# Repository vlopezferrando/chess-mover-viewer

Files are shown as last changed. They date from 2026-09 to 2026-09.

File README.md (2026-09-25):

# Chess mover CAD comparison

[Compare both layouts](https://vlopezferrando.github.io/chess-mover-viewer/).

- [A: battery beside servo — Ø43 × 21.0 mm](side-by-side/): compact 100 mAh catalogue cell, KST X06N and 13 mm wheels.
- [B: battery below motors — Ø43 × 25.2 mm](bottom-battery/): Honcell 100 mAh cell and 20 mm wheels.

Both retain 6 mm magnet travel, front charging pads and a separate dock. Camera position/opening are improved; the viewers include a camera-field inspection mode. STEP downloads are available in each viewer.

[Design comparison, sources and validation](LAYOUT_COMPARISON.md).

Earlier designs: [stacked battery](battery-stacked.html), [plate-powered KST](43mm-kst-plate.html), [43 mm FS0307](43mm-fs0307.html), [45 mm](45mm.html), [40 mm](40mm.html).

Nominal CAD validation passed; electrical performance, supplier-specific cell packaging, docking retention, optical performance and fabrication tolerances remain unqualified.

Latest: [coplanar mover with wall rails](https://vlopezferrando.github.io/chess-mover-viewer/rail-dock/). See [rail concept](RAIL_DOCK.md) and [body/PCB readiness](BUILD_READINESS.md).

Detailed body: [viewer](https://vlopezferrando.github.io/chess-mover-viewer/detailed-body/), [design notes](BODY_DESIGN.md), [supplier brief](BODY_PRINT_BRIEF.md). Ø44 × 21 mm fit prototype, not a manufacturing release.

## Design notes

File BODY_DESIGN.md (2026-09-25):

# Detailed coplanar body — first fit prototype

This revision turns the packaging concept into **three separate body parts with recessed underside fasteners, motor stops, integral axle bridges, a servo/battery carrier, a camera nest and PCB capture ledges**. It is a fit-and-assembly prototype for supplier review. It is not a released powered mechanism or a finished PCB design.

## Dimensions and deliberate changes

- **Ø44 mm × 21 mm**, retaining 21.2 mm nominal floor-to-board space and 13 mm wheels. Three Ø3.6 mm screw posts need up to a 44 mm envelope at the selected clear locations; this is a local packaging result, not proof that no possible 43 mm body exists. The front is flattened at Y=-21.5 mm to preserve the rail interface.
- Battery remains beside the servo, with the existing assumed **17.6 × 14.6 × 8 mm design envelope**. Its bottom moves from 11.6 to **12.1 mm**, leaving 0.1 mm nominal roof clearance. This is *not* a confirmed swollen-cell tolerance: supplier dimensions remain a release blocker. Do not clamp a real pouch cell into an undersized pocket.
- Main shell wall **1.2 mm**, floor **0.6 mm**, lid **0.8 mm**. Wheel/optical openings and local reliefs mean those are design dimensions, not a global minimum-thickness certification.
- Equipment shelf **1 mm**; a solid **0.8 mm servo bed** reinforces it without increasing height. It replaced two narrow ribs after the first stiffness screen. Battery shelf and side/end guards retain the cell without using it as a structural support for the servo.
- Axle bridges: two **1.5 × 2.8 mm arms** per wheel, with Ø3.2 mm nominal bores. Actual axle/gear coupling and axial retention remain undecided.
- Left rear coil moves from (-11.2,13.3) to **(-12.4,12.4) mm**, 1.5 mm displacement, to clear the lid's lift-guide socket. No coil electrical design is implied.
- Camera nest supports the existing sensor/lens envelope above the entrance pupil. It does not establish a selected camera or a confirmed retention/adhesive method.
- Three low-friction anti-tip pads are modeled with **0.1 mm nominal floor clearance**. The wheels remain the nominal floor contacts; slight pitch brings a pad into contact. Actual tire compliance, pad height, floor flatness, wheel load share and traction need measurement.

## Body joint and manufacturing detail

1. **Lower chassis**: open-top motor saddles, axial end stops, integral outboard axle bridges, front charging-contact carrier and magnet pocket, three screw-bearing seats and pad recesses.
2. **Removable equipment carrier**: servo bed and case stops, battery shelf/guards, camera nest, PCB ledges, peripheral wall. Its stepped underside mates with the chassis with a **0.1 mm nominal axial seam**; this is subject to coupon calibration.
3. **Lid**: PCB capture surface, three deep threaded bosses and two lift-guide sockets. Two separate elastomer pads apply provisional servo restraint; their free/compressed dimensions are assumptions and require measured preload.

Three nominal **M1.6 × 16 socket-head screws enter from underneath**: Ø3 × 1.6 mm heads sit in open Ø3.7 mm access pockets, with bearing seats at Z=4 mm. Ø1.8 mm clearances pass through the chassis/carrier. The lid has Ø3.56 mm bosses extending down to Z=15 mm, with through Ø1.25 pilot bores intended for **post-print M1.6 tapping**, not printed threads. Nominal thread engagement is **5 mm**, and screw tips finish 1 mm below the roof. This avoids the weak thin-walled counterbore collars of an initial top-entry trial. The threaded boss has about **1.15 mm radial material** around its pilot.

No installation torque or pullout capacity is qualified. Test the resin/thread process on the coupon before assembling the body. See [HPC's screw dimensional reference](https://shop.hpceurope.com/pdf/gb/CHC.pdf); select an actual available screw/material before ordering hardware.

The lid guide sockets have **0.4 mm nominal radial walls** (Ø2.5 outside, Ø1.7 bore), and only about 1 mm pin bonding length. They are explicitly a delicate feature requiring supplier review and retention/load tests. If unsuitable, use separate metal bushings or enlarge/reposition these mounts; do not infer strength from successful STL export. The print pack excludes the small gears, wheels, crank, tray and pins because their manufacturing interfaces are not yet detailed.

Charging contacts remain custom spring envelopes; the new carrier anchors their support to the chassis. Power rail force, contact wear, magnet retention/release and electrical charging remain unvalidated. The PCB outline now reserves screw/guide clearance and a through-pocket over the raised battery; the largest connected board region is retained. It is still not routed or proof that all circuitry fits.

## Assembly sequence to evaluate

1. Inspect and calibrate bores/joints using the coupon. Clean/cure parts using the service's specified process, tap pilot holes and verify them with screws before installing electronics.
2. Install the reference motor/gear/wheel/axle assemblies in the lower chassis; verify end-stop and saddle fits. **Shaft shortening, wheel/gear fixation and axle end retention still need exact manufactured parts**, so this currently means a fit trial, not permission to run loose gears.
3. Assemble the servo, crank, pin and magnet carriage as a module **outside the carrier**. The reference crank has no completed spline/pin-retention detail. This subassembly must be engineered before a powered build; the body assumes it can be supplied as an assembled module.
4. Lower that module into the separate equipment carrier. Fit the camera into its nest and place the battery with its leads through the rear guard openings. Establish real sensor and cell retention after selecting those parts.
5. Place the equipped carrier onto the motor chassis, with calibrated motor shims. Route leads before closing: shown channels are allowances, not a complete harness design. The body must not pinch leads or press battery terminals against the shell.
6. Place the PCB on the ledges, then lower the lid and its guide pins through the guide clearances/carriage. Hold the stack in a soft assembly fixture and install the three screws from underneath through the checked tool paths. First dry-assemble without the battery so loose parts cannot fall onto it. Test the actual guide fit before bonding pins.
7. Verify unpowered wheel freedom, lift travel, contact alignment and camera view. Perform load/retention tests before powering motors or servo.

Sampled straight insertion checks cover the servo/lift module into an empty carrier, equipped carrier onto the chassis/drive, and lid/guide insertion with the remaining assembly present. They do not validate all manual operations, lead bends, finger access, camera adhesive, servo spline or the reference drivetrain's unresolved joints.

## Initial force calculations

`src/force_screen.py` uses SI units and writes JSON/CSV. It is **analytical screening, not FEA**:

- Existing magnetic sample: 0.366 N for a 10 × 2 N42 magnet at 3.6 mm gap and 4 mm lateral offset; motor/servo steel was absent from that simulation.
- With assumed 0.1 N guide resistance, 50% efficiency and factor 3: **12.50 mN·m lift torque screen**. This is not a measured worst-case demand or a check of the supplied servo voltage/duty cycle.
- Revised solid servo bed: approximately **0.009–0.046 mm deflection** across assumed E=1–2.5 GPa and 50–100% effective stiffness, versus a provisional 0.05 mm budget. Midspan beam stress is about 0.74–1.48 MPa; no allowable material strength or certified safety factor is assigned.
- Axle-arm screen: approximately **0.004–0.019 mm deflection**, sweeping assumed 30–60 g mover masses, 5 g vertical loading and equal wheel/arm sharing. Actual mover mass is not established.

The stepped servo-bed beam includes its thinner end sections. Its supports/load sharing and the axle-arm idealization still omit 3D notches, contact preload, warpage, creep, printed anisotropy and adhesive strength. These results justified geometry changes but do not qualify the body. Measure bed compliance, axle alignment, guide binding, thread pullout and the actual lift load in the assembled chassis.

## Reproduce

Use the pinned environment in `../cad_10_coplanar/requirements.txt` and the existing setup instructions in `../cad_01_mover/README.md`. At repository root:

```sh
MPLCONFIGDIR=/tmp/mover-mpl cad_01_mover/.venv/bin/python -m cad_13_body.src.build
cad_01_mover/.venv/bin/python -m cad_13_body.src.validate
cad_01_mover/.venv/bin/python -m cad_13_body.src.check_dock
cad_01_mover/.venv/bin/python -m cad_13_body.src.check_exports
MPLCONFIGDIR=/tmp/mover-mpl cad_01_mover/.venv/bin/python -m cad_13_body.src.camera_study
cad_01_mover/.venv/bin/python -m cad_13_body.src.force_screen
MPLCONFIGDIR=/tmp/mover-mpl cad_01_mover/.venv/bin/python -m cad_13_body.src.interface_drawing
cad_01_mover/.venv/bin/python -m unittest discover -s cad_13_body/tests
node cad_13_body/src/check_viewer.cjs
```

Open `output/mover_viewer.html` and choose **Inspect body parts** or **Explode body assembly**. The exploded view explains the structure, not a collision-free assembly trajectory. STEP assemblies, separate body STEP/STL, coupon, force screens and geometric reports live in `output/`. The STL ZIP is named **body_fit_prototype.zip** deliberately. Read [PRINT_BRIEF.md](BODY_PRINT_BRIEF.md) before requesting manufacture. No quote has been requested and nothing has been ordered.

## Final nominal checks

54 valid connected modeled parts; 12 lift poses, 24 insertion samples and three underside driver paths pass. Fifteen rail approach/parking samples pass. Each of the three body STEP files reimports as one valid solid within Ø44 mm; all four STL files (including coupon) are watertight under the mesh edge check. Intentional screw/pilot overlap represents unmodeled threads and is recorded separately. Camera geometric clear area is 118.4 mm² versus 110.1 mm² previously, under the same assumed lens model; actual optics remain unqualified. Three analytical-formula tests and the viewer-control stub pass; no live-browser rendering test was performed.

Build commands refer to the local engineering source workspace. This viewer repository contains exported artifacts, not a standalone copy of the complete source project.

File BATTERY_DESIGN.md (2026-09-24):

# Battery mover and charging dock — Ø43 × 25.2 mm

[Open the offline viewer](index.html). Use **Inspect battery**, **Show docking station**, the docking-distance slider, and the independent enclosure/lid layers. Downloads include [mover STEP](mover_step.zip), [dock STEP](dock.step).

This is a nominal packaging design. The battery is a documented reference cell, while charging electronics and dock contacts are space allowances, not a complete electrical or manufacturable design. Prior iterations remain unchanged.

## Dimensions and changes

| Quantity | Previous plate-powered KST | Battery version |
|---|---:|---:|
| Outside diameter | 43 mm | **43 mm** |
| Highest mover geometry above floor | 20.0 mm including contacts | **25.2 mm** |
| Floor-to-board underside | 20.0 mm | **25.4 mm** |
| PCB top | 19.0 mm | 24.4 mm |
| Servo case top | 18.8 mm | 24.2 mm |
| Magnet / coil top | 19.5 mm | 24.9 mm |
| Camera lens height | 11.9 mm | **11.9 mm** |
| Magnet and stroke | 10 × 2 mm N42 / 6 mm | unchanged |
| Wheels | 13 mm | unchanged |
| Battery | none | 100 mAh, 1S, supplier-rated 2 A maximum continuous |

The 100 mAh cell sits horizontally above the drive motors. The servo, roof PCB and lift move upward together by 5.4 mm. Removing top/bottom sliding contacts means the new mover's highest geometry is its lid, 0.2 mm below the board underside. Thus the mover-height increase is 5.2 mm, and required floor-to-board space increases by 5.4 mm. The battery is not placed over the camera or in the magnet travel path.

The cradle includes edge guards and two hangers reaching the roof. A relief in the old motor saddle clears the shelf. The downward camera stays in place with longer supports and a flex routing allowance. Four top coils, KST X06, two N20 motors, transmission and optional shell remain. The front shell gains a recessed docking-pad carrier. Continuous upper/lower conducting sheets and all four sliding contacts are removed.

### Space budget

- Battery body: x = −16…13 mm; y = −8.25…7.25 mm; z = **11.6…16.35 mm**.
- Supplier maximum thickness: **4.4 mm at delivery, 4.75 mm after cycling**. The viewer uses 4.75 mm, not an unrealistically thin new-cell-only envelope.
- Shelf: z = 11.2…11.5 mm; **0.3 mm above the nominal motor top**, and 0.1 mm below the cell. This thin shelf still needs strength and insulation design.
- Lowest servo rail: z = 16.6 mm, leaving **0.25 mm over the cycled cell envelope**. Do not clamp or load the cell with the servo.
- Straight battery tab allowances: maximum **7 mm length and 2.2 mm width**; nominal tab spacing represented. Weld insulation, tab-location tolerances and final lead bends require supplier confirmation. We do not assume folded tabs save space.
- Added electronics allowances: **9 × 6 × 1.4 mm** charger/protection/charge-tracking area and **6 × 7 × 2 mm** boost-converter/inductor area. Existing ESP32, motor-driver and memory allowances remain. These are not validated component placement/routing or thermal results.
- A local height study compares 25.2, 25.0 and 24.8 mm while preserving this shelf and moving the upper mechanism. The 25.0 mm trial leaves only 0.05 mm battery-to-rail clearance; 24.8 mm overlaps. The selected 25.2 mm uses a provisional 0.25 mm nominal gap. This is **not a full manufacturing tolerance budget or proof of a global minimum**.

See `output/space_study.json` and `output/height_comparison.csv`. The old 20 mm upper layout is also tested against the new cell envelope, exposing its collisions. A larger diameter might permit side-by-side repacking; that search is outside this local study.

## Reference battery and power constraints

Reference: **Honcell HCG431528HP20 / HCG-431528**, 100 mAh, 3.7 V nominal, approximately 2.9 g, bare cell. [Manufacturer page](https://www.honcell.com/lithium-battery/cells/hcg-lipo-battery-cells/1933) and [2024 manufacturer datasheet](https://www.honcell.com/Public/Uploads/uploadfile/files/20240809/DATASHEETHCG4315283.7V100mAhCELL2024.pdf); saved in `sources/honcell_100mah.pdf` with an inspected drawing render. Dimensions include the complete body/seal envelope, but exclude the separately modeled tabs.

The sheet specifies 2 A maximum continuous discharge at 10–45°C. Its 4 A pulse figure is only **2–3 milliseconds**; it is not permission to run stalled motors at 4 A. The final motor winding, drive-current limiting, converter losses, servo transient and coil load must fit the battery budget. At 3.0 V and 85% converter efficiency, 2 A would provide only 5.1 W; practical limits need margin for voltage sag and temperature. The reference cell is not yet purchased or electrically tested.

Use a regulated servo supply: a 1S cell cannot provide a steady 6 V. Reserve cell protection, temperature sensing, charger power-path management and reverse-current blocking. CAD does not implement these circuits. No battery connector is claimed to fit; supplier-welded tabs/leads are represented, with service access requiring detail design.

A 150 mAh cell is not automatically interchangeable. The sourced [Blade BLH4210 150 mAh high-discharge battery](https://www.horizonhobby.com/product/150mah-1s-3.7v-45c-lipo-battery-ph-1.25-ultra-micro/BLH4210.html) is 42 × 12 × 5 mm: its 43.68 mm footprint diagonal exceeds the 41.4 mm shell bore. This build therefore implements the documented **100 mAh** reference. A shorter 150 mAh alternative would require its own drawing and clearance checks.

## Docking contacts and operation

Two **3 × 3 mm mover pads**, on 7 mm centre spacing, face forward (−Y). Their exposed plane is y = −20.5 mm, with z centre 9.5 mm. They are recessed within the 43 mm circular envelope and connect to the **charger input**, not directly across the bare battery. Polarity in the model: x = −3.5 is GND; x = +3.5 is +5 V. PCB-mounted or flex-mounted plated pads on an insulating carrier are intended; finish, termination and fastening are provisional.

The external dock has two axial spring-contact envelopes and approach rails. Spring barrels are on the station, saving mover volume. Modeled compressed tips touch the pad planes. The concept allocates approximately 1 mm working compression, but no purchased contact, spring rate, retention force or free-tip CAD has been selected. The 1.2 mm tips have a geometric ±0.9 mm pad-centering allowance before an entire tip leaves a 3 mm square; this is not demonstrated docking accuracy. The nominal dock footprint is 50 × 31 mm, outside the mover boundary.

The viewer's docking slider moves the mover 0–45 mm along +Y away from the seated pose. This is ideal kinematic inspection, not automatic navigation. `check_dock.py` tests sampled straight approaches against the fixed, compressed dock geometry and verifies pad/tip surface alignment. It does not simulate contact compression, yaw error, bounce or electrical connection. **A passive detent or other holding arrangement is still needed** if spring force can push the mover away; holding stalled drive motors while charging is not assumed acceptable. The shell and dock remain concept geometry, not ready-to-print fixtures.

Intended charging sequence: lower magnet, approach a perimeter marker, align slowly, establish contact, confirm input voltage/charge status, disable drives and sleep unnecessary loads, then undock with an energy reserve. Tentative standard charge current is **100 mA (1C)**; full CC/CV charging is not instantaneous. Temperature limits and supplier initial-charge instructions apply. The 200 mA maximum rating is not the default charging setting. Each mover requires its own charge controller. Low-battery detection should combine voltage under known load with charge tracking; voltage alone during acceleration is not a precise state-of-charge estimate.

## Magnet, coils and remaining limitations

Without the former 0.1 mm copper layer, nominal magnet-to-steel distance is **3.5 mm engaged and 9.5 mm retracted** (0.5 mm clearance + 3 mm nonmagnetic board + lift). Existing magnetic force/release calculations used 3.6/9.6 mm; they have **not** been rerun or requalified here. Battery pouch metal, motor steel, servo gears and PCB copper remain omitted from that FEM. Coil resonance, battery heating and RF behaviour need measurement in the new stack.

The previously targeted **150 mm/s** is retained but not demonstrated. Battery current limits could affect acceleration and available torque. Full tolerance stack, heat flow, pouch protection, wire bends, fasteners, snap features, servo-horn retention, optical field of view and close focus remain unresolved. Carry forward the KST crank/spline and thin carrier limitations in [iteration 8](https://github.com/vlopezferrando/chess-mover-viewer/blob/main/ACTUATOR_STUDY.md).

## Reproduce and validation

From the repository root:

```sh
cad_01_mover/.venv/bin/python -m cad_09_battery.src.build
cad_01_mover/.venv/bin/python -m cad_09_battery.src.validate
cad_01_mover/.venv/bin/python -m cad_09_battery.src.space_study
cad_01_mover/.venv/bin/python -m cad_09_battery.src.check_dock
cad_01_mover/.venv/bin/python -m cad_09_battery.src.check_step
node cad_09_battery/src/check_viewer.cjs
```

Uses the pinned CAD dependencies in `requirements.txt`, the original motor asset and earlier gear/mesh utilities. Geometry dimensions are in millimetres. `parameters.json` is generated metadata, not a separate input file. `build.py` is the authoritative parametric layout.

Reports in `output/`: part validity/connectedness and interference checks, 23 lift poses, 26 gear phases, cylindrical containment, camera centre path, STEP round-trip, local height study, nine dock-approach poses and viewer-control checks. Overlap reporting threshold is 0.01 mm³. These are sampled nominal geometry checks, not continuous-motion or fabrication qualification. Viewer controls use DOM/WebGL stubs; static PNGs are visually inspected. No real-browser rendering test is claimed.

The selected build passed all listed nominal checks: 52 valid connected mover solids, no reported static/lift/gear overlaps, 43 × 43 × 25.2 mm STEP bounds, clear camera centre path and nine clear sampled dock approaches. The local 25.0/24.8 mm alternatives fail the selected battery-clearance criterion. Static overview, battery, docking and underside previews were visually inspected.

Shared viewer: https://vlopezferrando.github.io/chess-mover-viewer/ . Earlier plate-powered KST version: `43mm-kst-plate.html`.

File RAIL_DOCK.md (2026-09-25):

# Coplanar mover with wall-rail charging

Chosen architecture: Ø43 × 21.0 mm, 21.2 mm floor-to-board, 100 mAh catalogue battery beside KST X06N, 13 mm wheels, 10 × 2 mm piece magnet with 6 mm lift. This is a **packaging concept, not a manufacturing release**. Existing battery, lens, motor, PCB and structural caveats from [iteration 10](LAYOUT_COMPARISON.md) still apply.

## Charging arrangement

Two mover contacts share a vertical column at X=0, facing the front wall:

| Element | Height above floor | Nominal geometry |
|---|---:|---|
| Separate retaining magnet | 4 mm centre | Ø3 × 1 mm; packaging placeholder |
| GND contact | 8 mm centre | Custom compliant leaf allowance |
| +5 V charger input | 13.5 mm centre | Custom compliant leaf allowance |

The station has 100 mm long horizontal rails, 2.4 mm high, separated by insulating backing, plus a separate 3.4 mm high passive steel strip. The magnet-to-steel gap is 0.95 mm at the seated pose. Two insulating strips limit nominal overtravel against the shell. Rail materials/finish, contact material, preload, magnet grade/force, fasteners and tolerances remain unspecified. The spring geometry depicts a nominal seated position; it is neither a purchased part nor an elastic calculation. Its 6 mm leaf span and 0.08 mm thickness are packaging allowances only. The square tip is a stand-in for a rounded wiping contact.

The mover can park **anywhere along an equipped straight wall, facing it**. This is not charging at arbitrary room positions or headings. Wall corners, rail joins, yaw capture and end stops need separate design. Neither a continuous steel strip nor a round shell passively selects the correct heading: floor-marker navigation must align it. The along-rail slider illustrates different parking positions, not a sliding-while-charging recommendation.

Recommended first experiment: small recessed mover magnet against passive steel, with gold-plated low-force wiping contacts. Keep retention electrically separate from the power rails. Tune the retaining force through recess/gap changes. The displayed 3 × 1 mm magnet has **no verified force prediction**. Do not order it solely from this CAD.

## Why not just magnetic tape on the wall?

Magnetic rails exist. [FIRST4MAGNETS](https://www.first4magnets.com/comparing-our-flexible-adhesive-range) distinguishes ferrite magnetic tape, neodymium magnetic tape and passive steel tape. Magnetic tape plus a steel mover keeper is a plausible alternative that removes the extra permanent magnet from the mover. However, holding force varies with material, pole pattern, overlap and gap, and introduces a permanent magnetic field along the wall. Discrete wall magnets could instead produce preferred docking locations. Passive steel still interacts with the piece-carrying magnet, so either arrangement requires a full-assembly magnetic check, especially with that magnet lowered. Extra mover magnets can also attract other movers and ferrous debris; weak retention is preferable.

Compact commercial contacts are not automatically soft: [Harwin's catalogue](https://cdn.harwin.com/pdfs/Harwin_Product_Catalog_page_278.pdf) lists 0.49 N working force for S7131-45R. Two such contacts would require roughly 0.98 N just to counteract their springs. This is an example, **not a selected part**. A smaller current requirement does not itself guarantee a reliable low-force contact.

A holding magnet must exceed both contact spring forces plus disturbance margin. During retreat, springs initially assist separation; after they unload, the wheels must overcome the remaining magnetic attraction. Thus evaluate the entire force-versus-distance curve:

`required wheel force(d) = max(0, F_magnet(d) - sum(F_spring(d))) + rolling resistance`

Compare it with `min(2 * wheel_torque / wheel_radius, tire_mu * driven_wheel_normal_load)`. Motor torque, tire friction and wheel load are not yet measured. Also check pitch moments because the retaining magnet and contacts act at different heights; the nominal insulating stops do not prove stability. Pull ratings at ideal contact cannot establish this result: [K&J's test explanation](https://www.kjmagnetics.com/blog/testing-magnet-strength) describes thick steel and zero-gap conditions and the effect of gaps.

Bench acceptance: both contacts remain inside their rated compression range, contact voltage drop is within charger headroom, charging is stable across repeated placements, and the mover backs away at low battery without wheel slip. Test rail dirt/oxidation and tolerance extremes. Use current-limited rail supply, input protection and a real 1S charger/protection circuit, not direct battery connection. Rail current must cover simultaneously docked movers. Set charge current from the actual cell specification; 100 mAh capacity is not a charge-current rating. Exact supply, charge current and circuit remain undecided.

## Reproduce and inspect

Use the existing CadQuery environment from `cad_01_mover/README.md`, at repository root:

```sh
MPLCONFIGDIR=/tmp/mover-mpl cad_01_mover/.venv/bin/python -m cad_12_rail_dock.src.build
cad_01_mover/.venv/bin/python -m cad_12_rail_dock.src.validate
cad_01_mover/.venv/bin/python -m cad_12_rail_dock.src.check_dock
cad_01_mover/.venv/bin/python -m cad_12_rail_dock.src.check_step
MPLCONFIGDIR=/tmp/mover-mpl cad_01_mover/.venv/bin/python -m cad_12_rail_dock.src.camera_study
node cad_12_rail_dock/src/check_viewer.cjs
```

Open `output/mover_viewer.html`; choose **Show docking station**, then **Position along wall rail**. STEP assemblies, the rail assembly, shell STEP/STL files and checks are in `output/`. Shell STL export means a meshed CAD shape exists, not that the body is fabrication-ready. Existing and revised camera silhouettes are compared using the same assumed 60° × 45° lens; real close focus and optical recognition remain unverified. Viewer checks execute controls against a stub, not an actual browser rendering test.

See [BUILD_READINESS.md](BUILD_READINESS.md) for what separates this layout from a printable functional body and a routed PCB.

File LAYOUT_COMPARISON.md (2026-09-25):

# Two battery layouts: side-by-side and below the motors

[Open A: side-by-side](side-by-side/index.html) · [Open B: bottom battery](bottom-battery/index.html) · [Camera comparison](side-by-side/camera_comparison.png)

Both are separate parametric CAD assemblies with STEP downloads, optional shell/lid, docking pads, a dock, full 6 mm magnet travel and 100 mAh reference batteries. They are packaging candidates, not production-ready or electrically validated hardware. The earlier stack remains in `cad_09_battery`.

## Result

| Quantity | Previous stack | A: battery beside servo | B: battery below motors |
|---|---:|---:|---:|
| Diameter | 43 mm | **43 mm** | **43 mm** |
| Mover height | 25.2 mm | **21.0 mm** | **25.2 mm** |
| Floor-to-board spacing | 25.4 mm | **21.2 mm** | **25.4 mm** |
| Wheel diameter | 13 mm | 13 mm | **20 mm** |
| Motor shaft height | 5.9 mm | 5.9 mm | **11.3 mm** |
| Camera lens height | 11.9 mm | **12.8 mm** | **16.0 mm** |
| Camera XY | (5, −13.5) | (0, −15.8) | (0, −15.8) |
| Floor window | Ø10 mm | **16 × 10 mm ellipse** | **16 × 10 mm ellipse** |
| Geometrically visible floor, assumed 60° × 45° lens | 61.8 mm² | **110.1 mm²** | **125.4 mm²** |
| RPM required for 150 mm/s, 1:1 transmission | 220 | 220 | **143** |

A saves **4.2 mm / 16.7% height** versus the previous battery stack. Motors remain in the lower layer; battery and servo share the upper layer. B trades height for larger wheels, a higher camera and a low battery. It does not reduce height versus the previous stack.

## A: put a thicker, shorter battery beside the servo

The previous thin cell's 29 × 15.5 mm body is awkward to pack beside the actuator. A manufacturer catalogue lists **LiPol LPHD7214017**, 100 mAh, 20C, **17 × 14 × 7.2 mm**. Its thicker body occupies much less plan area. Source: [LiPol manufacturer catalogue](https://www.lipolbattery.com/High-Discharge-20C-Lithium-Polymer-Battery-for-Camera-Drone.html), preserved as `sources/lipol_catalogue.html`.

This is a **catalogue candidate**, not a selected production cell. No individual supplier drawing, tab dimensions, availability confirmation, temperature-dependent discharge data or cycled-thickness specification has been obtained. The CAD uses an explicit **17.6 × 14.6 × 8.0 mm design envelope**, allowing 0.6 mm extra length/width and 0.8 mm extra thickness. These allowances are engineering assumptions, not manufacturer-certified tolerances or guaranteed swelling clearance. Another 3 mm is reserved at the terminal end. A suitable factory-wired version and real sample measurements are prerequisites for fabrication.

The battery is rotated 90° in plan, centred at (9.6, −1.2), z=11.6…19.6 mm. Its insulating shelf starts at z=11.2; side guards are relieved around the right wheel. The shelf-to-wheel gap is only about 0.1 mm at the nominal inner tire face; that is aggressive and needs tolerance allocation. The battery is not squeezed under the servo. The upper production PCB has a separate battery pocket.

The servo/lift group moves 2.6 mm left and 2 mm forward. Both alternatives now use **KST X06N**, the factory tabless version, rather than silently deleting the standard X06's tabs. A drawing-derived 20 × 16.6 × 7 mm case, 5 mm shaft offset, 2.7 mm projection and 4 mm shaft envelope are included. The shaft adapter still needs a real spline/retaining screw design. Source: [KST X06N manufacturer page](https://kstservos.com/products/x06n-v6-0-hv-micro-digital-metal-gear-glider-1-8kg-torque-servo-motor) and [manufacturer drawing](https://cdn.shopify.com/s/files/1/0570/1766/3541/files/X06N_V6.0_Technical_Specifcation.pdf?v=1700472342), saved and visually inspected in `sources/`.

A's servo occupies z=13.0…20.0 mm, overlapping the battery's vertical interval. The motors still occupy the lower region, because placing their long 32 mm shaft-inclusive shapes, the servo and battery all in the same layer was not established. The new cradle has a bridge around the left wheel and needs engineered attachment/retention. The carved PCB is one connected solid; an isolated scrap crescent is discarded. Electrical routing, RF keep-outs and board stiffness have not been proved.

The packing screen varies planar translation/rotation using conservative projected servo, crank, guide and battery shapes. It tried 29 × 15.5, 22 × 15, 17 × 14 and 15 × 15 mm battery footprints. The selected tabless arrangement was subsequently adjusted and checked in exact 3D. Nonzero search penalties are **not proofs of impossibility**, and this is not a global minimum-height proof. Reports: `output/packing_search.json`, `packing_diameters.json`, `packing_tabless.json`.

## B: battery under the drive motors, larger wheels

B retains the better-documented **Honcell HCG431528HP20 100 mAh cell**, with its **29 × 15.5 × 4.75 mm cycled envelope**, now at z=1.2…5.95 mm. The motor body bottoms are z=6.3 mm: **0.35 mm nominal vertical clearance**. The cradle is insulating; electrical insulation, puncture/crush protection and assembly tolerances require detail design. [Honcell source](https://www.honcell.com/lithium-battery/cells/hcg-lipo-battery-cells/1933); the saved full datasheet is in `cad_09_battery/sources`.

The 20 mm wheels have centres at z=10 mm and remain inside the Ø43 footprint. Motor axes rise to 11.3 mm. Motor lateral offsets and gear phase are recalculated to preserve the **6.2 mm gear centre distance** with the 1:1, 31-tooth transmission. The wheel openings grow accordingly. Sampled gear meshing and enclosure containment are checked again.

**Full 7 mm straight cell tabs collide with the larger right wheel.** This alternative explicitly requires supplier-trimmed tabs with welded flexible leads: CAD represents a 2.8 mm terminal allowance. It does not assume a user should fold, solder directly to or modify a bare pouch. Lead routing/strain relief is not finalized and the supplier configuration must be confirmed. The cell is not yet a fully packaged, protected battery assembly.

Larger wheels give **54% more linear speed at the same RPM**, but only **65% of the wheel force at the same axle torque**. 150 mm/s requires about 143 RPM instead of 220 RPM. This is kinematics, not a claim that the selected motor/battery can deliver the required loaded speed. Motor winding, current limits, magnetic drag, drivetrain losses and tire traction are still unknown.

## Does the low battery improve stability?

Lowering a battery helps if the other masses stay put. Here, the motors and upper assembly move up. `src/compare.py` makes the competing moments explicit rather than claiming a tipping result.

For an illustrative comparison with two 10 g motors, a 6 g servo and equal 3 g battery masses:

- Moving the battery centre from 15.6 to 3.575 mm changes vertical mass moment by **−36.1 g·mm**.
- Raising both motors 5.4 mm adds **108 g·mm**.
- Raising the servo 4.2 mm adds **25.2 g·mm**.
- Net change for just these components is **+97.1 g·mm**: the larger masses more than cancel the lowered battery.

The sensitivity table uses 6–12 g per motor and 2.5–4 g equal battery masses. All tested cases increase this partial vertical mass moment. These masses are explicit assumptions (apart from the nominal KST mass); the cells differ, other components are omitted and no whole-mover centre of gravity is claimed. Larger-wheel mass would also need accounting. Compared with A, B is therefore **not automatically more stable**.

The two inline wheels do not by themselves define a stable fore/aft support polygon. Final glides/casters or controlled shell contact, ground clearance, tire compliance and magnetic loading must be specified before a tipping simulation or stability guarantee. The current shell has 0.2 mm floor clearance. CAD collision clearance does not qualify rolling or rocking behaviour.

## Camera improvement and validation

Both cameras move to the front centre. The original 4 mm lens and 6 × 6 mm sensor island envelopes are retained. The floor cutout becomes a 16 × 10 mm ellipse centred at (0, −14.8). Camera connectors, flex and front electronics are repacked. This creates more usable view without inventing a thinner lens.

`src/camera_study.py` projects every non-camera mover triangle between the assumed entrance pupil and the floor, including motors, cradle and shell. Green pixels in the comparison mean an unobstructed straight ray; red means an obstruction. The comparison assumes **60° horizontal × 45° vertical FOV**, solely as a common test. At 240 × 240 samples, visible floor increases by about **78% for A** and **103% for B** relative to the previous geometry. The unclipped view rectangles are about 14.8 × 10.6 mm for A and 18.5 × 13.3 mm for B, but substantial portions remain blocked.

Doubling raster resolution from 120 to 240 changes estimated visible area by under **0.18%** across all three cases. Unit tests check unobstructed views, rejection of objects above the camera, and a known perspective shadow area. This is not a lens model: focus at 13–16 mm, entrance-pupil location, sensor aspect ratio, distortion, illumination and marker decoding all require hardware tests. Increasing physical field coverage can reduce pixels per marker.

The viewer's **Inspect camera view** button shows assumed cyan ray boundaries and the real surrounding geometry. The rays themselves are not clipped; use the comparison image for the occluded regions.

## What remains provisional

Both keep 10 × 2 mm N42 magnets, 6 mm vertical travel, four coils, production-electronics allowances, front charger pads and an external dock. Nominal magnet-to-washer gaps are 3.5/9.5 mm for a 3 mm board and 0.5 mm air clearance. Existing FEM used 3.6/9.6 mm and omits the battery/motor/servo metal; new magnetic or resonance simulations were not performed.

Power electronics are reserved volumes, not routed circuits. The small-cell current budget still requires measurement and protection/current limiting. Dock springs remain envelopes: preload, passive holding/detent, contact bounce, strain relief and autonomous navigation are unqualified. All supports, fasteners, servo cradle bonding/clamping, PCB seams and manufacturing tolerances require detailed engineering. No battery or servo has been purchased or modified.

For a compact first prototype, **A is the preferred packaging direction**, conditional on confirming the compact cell. B is a useful alternative if larger wheels and camera clearance prove more valuable than the extra height. Neither is fabrication-ready.

## Reproduce

Use the existing CAD environment and pinned dependencies in `requirements.txt`. `src/layout.py` is shared by both alternatives; original motor CAD and older gear/lift utilities are imported from this workspace.

```sh
cad_01_mover/.venv/bin/python -m cad_10_coplanar.src.build
cad_01_mover/.venv/bin/python -m cad_11_bottom_battery.src.build
cad_01_mover/.venv/bin/python -m cad_10_coplanar.src.validate
cad_01_mover/.venv/bin/python -m cad_11_bottom_battery.src.validate
cad_01_mover/.venv/bin/python -m cad_10_coplanar.src.check_step
cad_01_mover/.venv/bin/python -m cad_11_bottom_battery.src.check_step
cad_01_mover/.venv/bin/python -m cad_10_coplanar.src.check_dock
cad_01_mover/.venv/bin/python -m cad_11_bottom_battery.src.check_dock
cad_01_mover/.venv/bin/python -m cad_10_coplanar.src.camera_study
cad_01_mover/.venv/bin/python -m cad_10_coplanar.src.compare
cad_01_mover/.venv/bin/python -m unittest cad_10_coplanar.tests.test_camera
node cad_10_coplanar/src/check_viewer.cjs
node cad_11_bottom_battery/src/check_viewer.cjs
```

Optional packing screen: `python -m cad_10_coplanar.src.packing_search --tabless` or `--diameter 45` with the CAD environment. Parameters are in the shared `config()` function; generated `parameters.json` files describe the outputs.

Each output directory contains engaged/half-servo-travel/released STEP, dock and docked assembly STEP, shell STEP/STL, a ZIP containing the engaged mover and dock, the offline viewer, PNGs, component CSV and validation reports. The 55° intermediate STEP is explicitly **half servo travel**, not half vertical stroke.

**Both final assemblies passed:** 51 valid connected mover solids each, Ø43 containment, correct 21.0/25.2 mm height, no reported static collisions, 23 sampled lift positions, 26 gear phases, clear camera centre path, nine nominal dock approaches and STEP reimport. Overlap threshold is 0.01 mm³. Viewer controls are tested with DOM/WebGL stubs and rendered previews were inspected; no real-browser rendering test is claimed. There is no continuous-motion, force, tolerance or production qualification.

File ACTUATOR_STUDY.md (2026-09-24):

# Smaller lift actuator: force and packaging screen

The FS0307 is already laid on its 8.3 mm side above the drive motors. A lighter servo does not necessarily reduce height: the smallest relevant case dimension matters. Changing the actuator also changes shaft position, supports and the cam/yoke geometry. This comparison was prepared for the iteration 7 FS0307 layout. Iteration 8 now incorporates KST X06 into nominal CAD; alternatives below retain their original sizing context. Hardware strength and performance remain unvalidated.

## Retraction load

Existing Simulation 5 predicts 0.231 N downward on the washer (equal upward on the magnet in the isolated model) for a centered 10×2 N42 magnet at 3.6 mm separation. At 4 mm lateral offset, it predicts **0.366 N**. Centered force alone would undersize the actuator. Both values assume the modeled washer and omit nearby motor/servo steel and conducting-plate dynamics.

For vertical slider displacement z=e cos(theta), the ideal shaft torque magnitude is `F * e * abs(sin(theta))`. Current stroke is 6 mm over 70–180 degrees, with e=4.471 mm. Using the largest sampled engaged force over the whole stroke and the maximum moment arm gives **1.64 mN·m**. This is a conservative envelope relative to those samples, not proof of a global force maximum. A sample at another gap/offset or actual chassis attraction could exceed it.

Sizing scenarios use `(F + guide resistance) * e / efficiency * design factor`:

| Assumptions | Required shaft torque, 10×2 magnet |
|---|---:|
| Magnetic load only | 1.64 mN·m |
| 0.05 N guide resistance, 70% efficiency, factor 2 | 5.32 mN·m |
| 0.10 N guide resistance, 50% efficiency, factor 3 | 12.50 mN·m |

Guide resistance and efficiency are assumptions, not measurements. The factors are engineering allowances, not a certified safety factor. Carrier gravity assists lowering; raising and acceleration need separate checks. Shaft-bearing lateral load, backlash, jamming, wear, and duty cycle also matter. The piece's full weight is not added to this lowering force: it remains supported by the board.

## Candidate actuators (manufacturer data checked 2026-09-24)

| Candidate | Case dimensions | Torque / force information | Assessment |
|---|---|---|---|
| FEETECH FS0307, earlier baseline | 20×8.3×17.3 mm | 49.0 mN·m stall at 4.8 V | Strong nominal margin; stall is not continuous torque. |
| AGFRC C017CLS | 13.5×6.2×16 mm | 6.37 mN·m stall at 3.7 V; 7.35 at 4.2 V | Smaller but marginal: moderate scenario approaches stall and cautious scenario exceeds it. Do not select without measured loads. Needs a regulated 3.6–4.2 V supply. |
| KST X06 | 20×7×16.6 mm | Manufacturer linked sheet gives 40 mN·m rated at 6 V; 150 mN·m stall | Best documented servo candidate for a modest reduction. Case thickness saves 1.3 mm; 19.8 mm overall height is only stack arithmetic, not checked CAD. Check delivered revision, shaft and tabs. |
| Pololu 2359, 700:1 sub-micro planetary gearmotor | Ø6×21 mm body, shaft additional | 90 RPM no-load at 6 V; gearbox instantaneous torque limit ~24.5 mN·m | Promising custom actuator, potentially 2.3 mm less body thickness than FS0307. Requires separate H-bridge, position/end sensing, mounting, cam coupling and holding strategy. No full-layout fit claim. |
| AGFRC C1.5CLS PRO linear servo | 21.4×15.2×6 mm; 9 mm stroke | Maker lists g·cm torque for a linear output | Useful shape, but published units do not establish linear thrust. Do not convert the torque listing into force without screw/gear data or a clarified thrust rating. Horizontal installation also needs a bellcrank/wedge to lift vertically. |

Pololu warns against exceeding the gearbox limit or stalling and recommends a brushed motor operating current generally at or below 25% of stall current. For the 2359, the cautious 12.5 mN·m scenario is below that gearbox limit; that is a screening result, not a continuous rating. Nominal 110-degree travel at 90 RPM takes 0.204 s unloaded, longer under load. Reduction gearing does not automatically guarantee self-locking. End-position sensing plus a mechanical dwell/latch could avoid sustained holding current. Do not use the attractive 0.9 kgf·cm motor stall figure as the permissible gearbox torque.

The linear servo and geared motor might help package components side-by-side; neither guarantees a thinner complete mover. Wheels remain a 13 mm lower bound, but the optical module, 6 mm magnet stroke and carrier, PCB and contacts impose other bounds. The 150 mm/s horizontal speed target does not set the lift actuator speed directly.

## Sources

- [FEETECH FS0307 specification](https://www.feetechrc.com/Data/feetechrc/upload/file/20220608/6379029528194935652722624.pdf)
- [AGFRC C017CLS manufacturer page](https://agfrc.com/index.php?id=2427). Page contains conflicting case-material text; verify the actual part drawing and sample.
- [KST manufacturer-linked manuals](https://kstservos.com/pages/user-manual), [linked X06 sheet](https://cdn.shopify.com/s/files/1/0570/1766/3541/files/X06-2021423-172520969.pdf?v=1660891701). Link is labeled V6 on the site but serves a 2021 document; confirm supplied revision before design freeze.
- [Pololu 2359 specifications and operating limits](https://www.pololu.com/product/2359), [dimension drawing](https://www.pololu.com/file/0J1831/sub-micro-plastic-planetary-gearmotor-dimension-diagram.pdf)
- [AGFRC C1.5CLS PRO manufacturer page](https://www.agfrc.com/index.php?id=2438)

## What to measure first

Measure retraction force versus gap with the actual washer, board, magnet and nearby steel, including lateral offsets. Measure guide breakaway friction and check for binding. Then run the candidate actuator at the intended supply voltage across repeated loaded cycles, recording current, travel time, temperature and endpoint repeatability. Choose rated operating torque comfortably above measured peak load; stall torque is not an operating target.

Reproduce the numerical sizing screen with `cad_01_mover/.venv/bin/python -m cad_07_43mm.src.actuator_study`. CSV/JSON results are in `output/actuator_loads.*`. This reuses existing FEM data; it is not a new FEM simulation of the assembled mover.

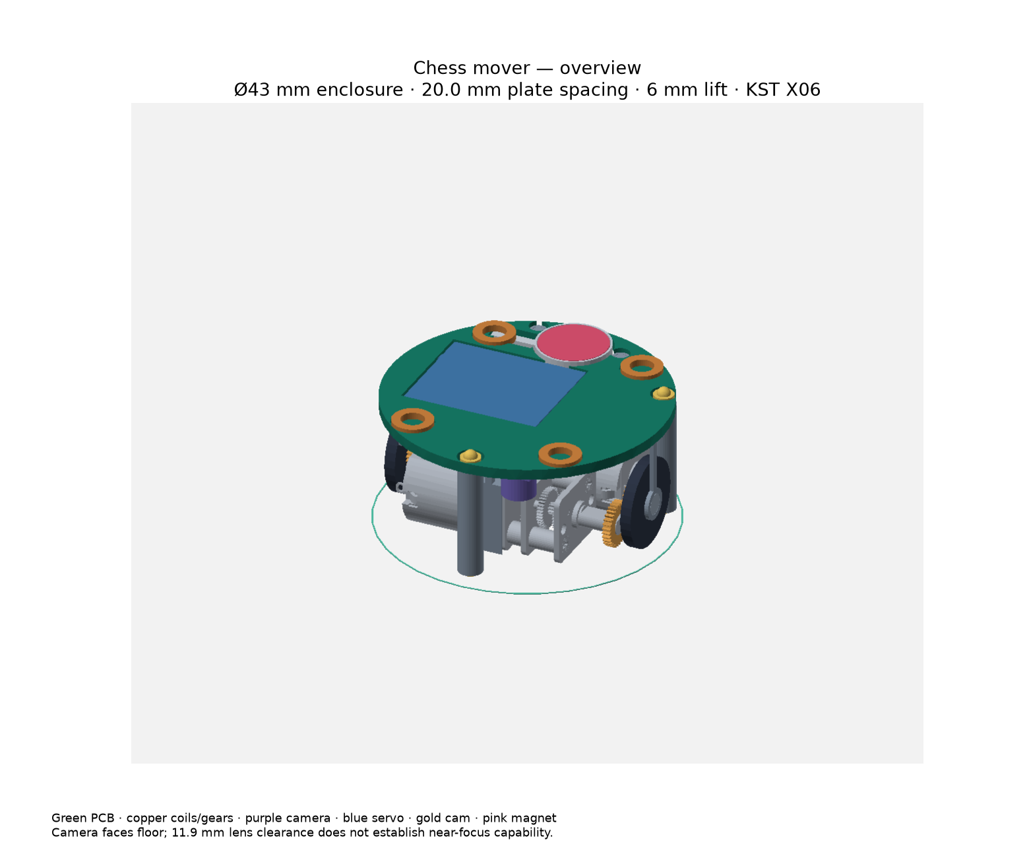
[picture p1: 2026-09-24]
overview-43mm-kst-plate.png

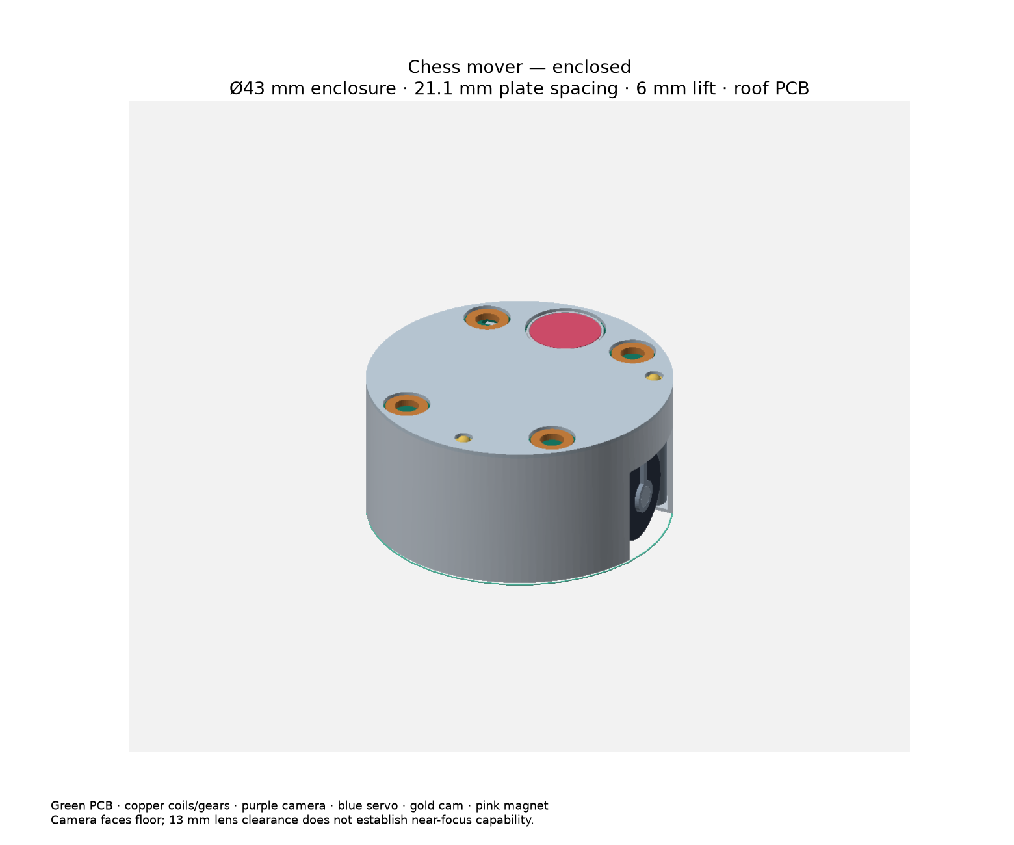
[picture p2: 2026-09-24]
enclosed-43mm-fs0307.png

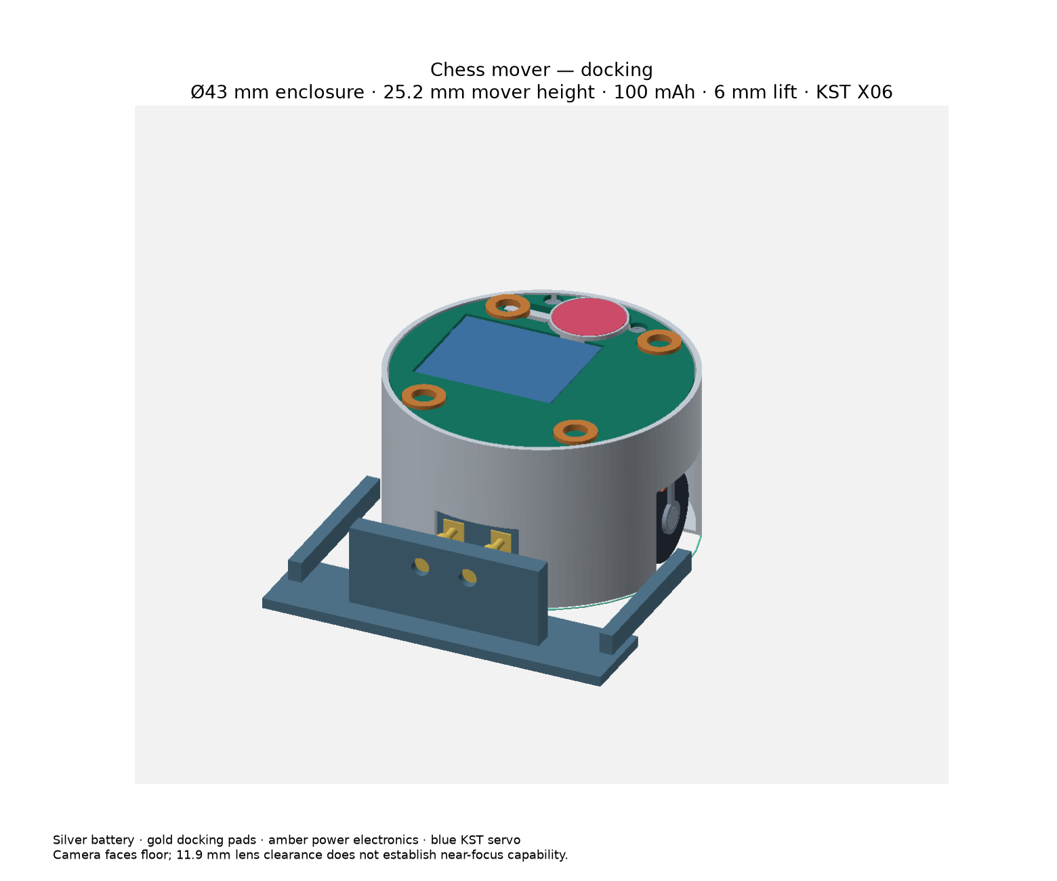
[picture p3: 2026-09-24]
docking.png

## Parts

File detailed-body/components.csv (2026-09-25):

name | kind | source | note
Right N20 motor | motor | Modified Pololu STEP | Motor winding/RPM unselected; shaft shortened.
Right 31T motor pinion | gear | custom/provisional geometry
Right 31T wheel gear | gear | custom/provisional geometry
Right independent axle | shaft | custom/provisional geometry | Extended Ø3 axle envelope. Wheel/gear fixation and end retention remain unresolved; not a production shaft drawing.
Right 13 mm wheel | wheel | custom/provisional geometry | Custom wheel; 150 mm/s not validated
Left N20 motor | motor | Modified Pololu STEP | Motor winding/RPM unselected; shaft shortened.
Left 31T motor pinion | gear | custom/provisional geometry
Left 31T wheel gear | gear | custom/provisional geometry
Left independent axle | shaft | custom/provisional geometry | Extended Ø3 axle envelope. Wheel/gear fixation and end retention remain unresolved; not a production shaft drawing.
Left 13 mm wheel | wheel | custom/provisional geometry | Custom wheel; 150 mm/s not validated
41 mm production PCB | pcb | custom/provisional geometry | Unrouted; separate pockets for battery and servo
Coil 1 | coil | custom/provisional geometry | Resonance not validated near metal components
Coil 2 | coil | custom/provisional geometry | Resonance not validated near metal components
Coil 3 | coil | custom/provisional geometry | Resonance not validated near metal components
Coil 4 | coil | custom/provisional geometry | Resonance not validated near metal components
ESP32-S3 bare IC | electronics | custom/provisional geometry
Dual H-bridge allowance | electronics | custom/provisional geometry
Memory allowance | electronics | custom/provisional geometry
Charger protection and fuel-gauge area | power | custom/provisional geometry | Reserved area, not a routed schematic
Boost converter and inductor allowance | power | custom/provisional geometry | Power/current/thermal qualification pending
Camera sensor island | camera | custom/provisional geometry
Downward lens | camera | custom/provisional geometry | 4 mm lens envelope retained; actual lens/focus not selected
Camera FPC connector | flex | custom/provisional geometry
Camera ribbon | flex | custom/provisional geometry
100 mAh battery design envelope | battery | LiPol LPHD7214017 catalogue | Catalogue 17 x 14 x 7.2 mm; model adds .6 mm length/width and .8 mm thickness. Not supplier-certified tolerances.
Battery termination allowance 6.6 | battery_wire | custom/provisional geometry | Provisional 3 mm termination space; vendor lead/tab drawing required
Battery termination allowance 12.6 | battery_wire | custom/provisional geometry | Provisional 3 mm termination space; vendor lead/tab drawing required
KST X06N tabless servo | servo | KST X06N manufacturer dimensions | Factory tabless X06N, not a cut-down X06. Cradle retention remains provisional.
Dock contact GND | dockpad | Custom concept; contact and magnet not qualified | Nominal compressed leaf + rounded-tip allowance (tip rendered square). Custom spring geometry, not a selected component.
Dock lead route GND | battery_wire | Custom concept; contact and magnet not qualified | Insulated wire/flex allowance
Dock contact 5 V | dockpad | Custom concept; contact and magnet not qualified | Nominal compressed leaf + rounded-tip allowance (tip rendered square). Custom spring geometry, not a selected component.
Dock lead route 5 V | battery_wire | Custom concept; contact and magnet not qualified | Insulated wire/flex allowance
Recessed docking magnet 3 x 1 mm | retention | Custom concept; contact and magnet not qualified | Axially magnetized toward wall; size is a packaging placeholder, pull force unverified.
Rear lift crank | cam | custom/provisional geometry | Reference mechanism envelope only. Servo spline, crank-pin bore and positive pin retention require a manufactured subassembly; not included in body print pack.
Captured rear pin | pin | custom/provisional geometry | Reference mechanism envelope only. Servo spline, crank-pin bore and positive pin retention require a manufactured subassembly; not included in body print pack.
Rear tray and captured yoke | lift | custom/provisional geometry | Thin carrier, guides and pin retention still need structural design
N42 magnet 10 x 2 | magnet | custom/provisional geometry | 6 mm release conditional on Simulation 5 force/friction assumptions; 150 mm/s following not qualified
Lower chassis with motor saddles | chassis | Custom first-detail CAD | Fit prototype; calibration and supplier review required
Removable upper equipment carrier | bridge | Custom first-detail CAD | Fit prototype; calibration and supplier review required
Screw-fastened lid | lid | Custom first-detail CAD | Fit prototype; calibration and supplier review required
M1.6 x 16 underside screw 1 | fastener | Custom first-detail CAD | Nominal DIN 912 envelope; threads simplified. M1.6 tapped lid boss prototype joint, pullout test required.
M1.6 x 16 underside screw 2 | fastener | Custom first-detail CAD | Nominal DIN 912 envelope; threads simplified. M1.6 tapped lid boss prototype joint, pullout test required.
M1.6 x 16 underside screw 3 | fastener | Custom first-detail CAD | Nominal DIN 912 envelope; threads simplified. M1.6 tapped lid boss prototype joint, pullout test required.
Servo compression pad -16 | liner | Custom first-detail CAD | Cut elastomer pad: .3 mm free, .2 mm modeled compressed. Preload to be measured.
Servo compression pad 0 | liner | Custom first-detail CAD | Cut elastomer pad: .3 mm free, .2 mm modeled compressed. Preload to be measured.
Motor shim (-8, -6.17) | liner | Custom first-detail CAD | Nominal shim under carrier; compression/adhesive thickness must be measured.
Motor shim (-8, 6.17) | liner | Custom first-detail CAD | Nominal shim under carrier; compression/adhesive thickness must be measured.
Motor shim (8, -6.17) | liner | Custom first-detail CAD | Nominal shim under carrier; compression/adhesive thickness must be measured.
Motor shim (8, 6.17) | liner | Custom first-detail CAD | Nominal shim under carrier; compression/adhesive thickness must be measured.
Anti-tip glide 1 | liner | Custom first-detail CAD | Cut low-friction pad, nominal .1 mm floor clearance; .05 mm adhesive allowance above. Not a caster or a validated traction model.
Anti-tip glide 2 | liner | Custom first-detail CAD | Cut low-friction pad, nominal .1 mm floor clearance; .05 mm adhesive allowance above. Not a caster or a validated traction model.
Anti-tip glide 3 | liner | Custom first-detail CAD | Cut low-friction pad, nominal .1 mm floor clearance; .05 mm adhesive allowance above. Not a caster or a validated traction model.
Rear lift guide -6.7 | support | custom/provisional geometry
Rear lift guide 6.7 | support | custom/provisional geometry

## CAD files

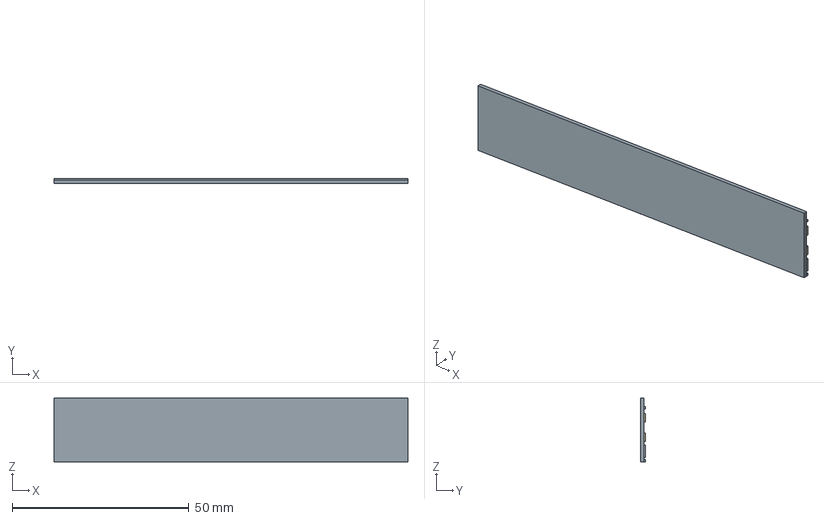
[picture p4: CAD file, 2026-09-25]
detailed-body/dock.step
100.0 x 1.50 x 18.0 mm
00_Insulating_wall_rail_backing
01_Continuous_charging_rail_GND
02_Continuous_charging_rail_5_V
03_Passive_steel_retention_strip
04_Insulating_compression_stop_1
05_Insulating_compression_stop_16

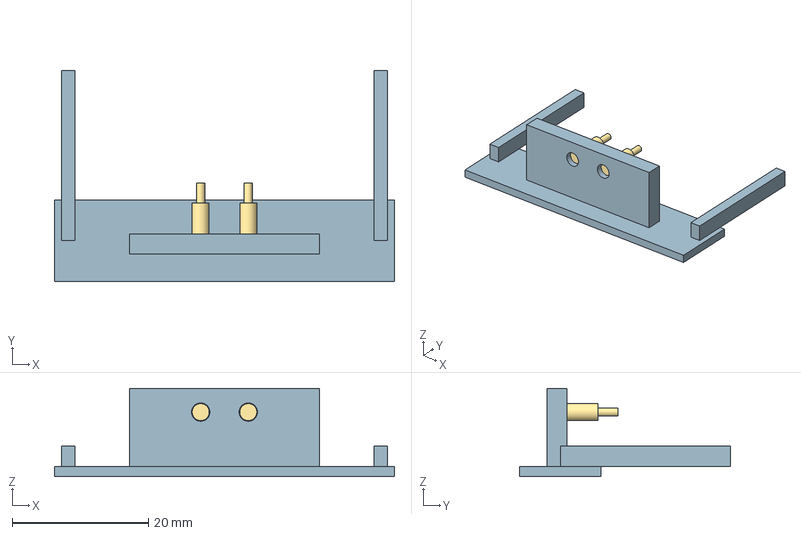
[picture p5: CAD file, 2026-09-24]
dock.step
50.0 x 31.0 x 13.0 mm
00_Dock_cradle_and_approach_rails
01_Dock_spring_contact_GND
02_Dock_spring_contact_5_V

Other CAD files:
bottom-battery/dock.step
rail-dock/dock.step
side-by-side/dock.step

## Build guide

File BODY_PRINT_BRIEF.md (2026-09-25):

# Supplier review / fit prototype — Barcelona

**Status: request-for-review package, not a manufacturing release for a working mover.** No files have been sent to a supplier. Dimensions are in millimetres. Do not apply automatic unit conversion or global fit scaling.

## Suggested service

Start with **INEO, Terrassa (Barcelona)**: [SLA service](https://www.ineo.es/es/?Itemid=148). Their published service covers locally produced resin technical prototypes. Ask them to recommend an engineering resin and review the delicate features, dimensional tolerances, cleaning and cure/orientation effects. Their page lists Accura Xtreme with a flexural modulus of 1.52–2.07 GPa, making it a candidate to discuss within the stiffness range screened here. That published range does not qualify these printed parts or their joints. This is a candidate supplier, not an endorsement based on a completed job or a quotation.

An alternative local route is [El Tucán's Barcelona printing service](https://eltucan.es/305-impresion-3d), which lists SLS PA11/PA12. The current small sockets and joints must be reviewed/revised for that process; this CAD is not claimed to be interchangeable across SLA and SLS without changes. [Formlabs' design guide](https://formlabs-media.formlabs.com/filer_public/a0/67/a06705a2-8065-4d99-8a5f-409fa01e684c/2401955-wp-enus-0.pdf) illustrates why feature guidance is tied to a particular machine/material/process rather than being a universal printability promise.

## Files / quantities

| File | Quantity | Purpose |
|---|---:|---|
| fit_coupon.stl | 1 initially | Check bores, tappability, thin walls and process bias |
| lower_chassis.stl | 1 after coupon review | Motor/axle support and lower body |
| equipment_carrier.stl | 1 after coupon review | Servo/battery/camera support and upper sidewall |
| lid.stl | 1 after coupon review | Threaded bosses, PCB capture and guide sockets |

STL tessellation tolerance is 0.025 mm for body parts. STEP files are also supplied for inspection and dimension checks. These files contain **no support structures**; supplier determines orientation/supports. Critical seating faces, bores, screw counterbores, guide sockets and battery pocket should be kept free of support scars where practical, with any required finishing agreed in advance.

## Review dimensions before accepting the job

- Envelope Ø44 × 21 mm; 1.2 mm main wall, 0.6 mm floor, 0.8 mm lid. Camera/wheel openings make local edges more delicate.
- Guide sockets: Ø2.5 outside / Ø1.7 bore, about 1 mm bonding length for nominal Ø1.6 steel pins. **0.4 mm radial walls require explicit review.** A metal-bushing redesign may be necessary.
- Axle bores: Ø3.2 nominal for a Ø3 reference axle; this is a printed-fit allowance, not a bearing specification. Roundness/coaxial alignment matter.
- Three Ø1.25 through pilots in the lid bosses, intended for M1.6 tapping; Ø1.8 shaft clearances and open Ø3.7 underside head-access pockets. Screw heads bear at Z=4 mm and nominal thread engagement is 5 mm. Threaded bosses are Ø3.56 mm outside. Ask whether the supplier can tap these holes and test a matching coupon. No heat-set inserts are specified.
- Main body seam: 0.1 mm nominal axial gap. Threaded-boss-to-carrier radial clearance 0.17 mm. Confirm realistic printed clearances before making a full set.
- Battery room includes assumed allowances but only 0.1 mm remaining top clearance. Obtain supplier maximum cell/lead/cycled dimensions first; do not force a cell into a printed part.
- Servo nominal 20 × 16.6 × 7 mm, lateral pocket allowance 0.2 mm. Verify actual X06N sample and lead exit. Shims/compression pads are separate materials, not printed features.
- Interference-free nominal assembly does not prove tolerances. If the proposed process cannot hold the required fits, report that and revise CAD; do not quietly scale the full assembly.

## Coupon map

Base: 42 × 24 × 2 mm. X positions -15,-9,-3,3,9,15 mm at Y=-4 mm have through bores **1.20, 1.25, 1.30, 1.70, 1.80, 3.20 mm**, respectively, in raised bosses. Thin walls at X=-12,-6,0,6,12 mm, Y=5 mm, are **0.4,0.6,0.8,1.0,1.2 mm** thick and 6 mm high. The layout map identifies the features; no dimensions are embossed into the small faces.

Measure after the specified full cure/conditioning. Record material, printer, layer settings, orientation, finishing and measured sizes. Test tapping/assembly on the coupon, then adjust individual CAD fits rather than globally scaling the model.

## Message the user can send (not sent)

Hola, estoy desarrollando un pequeño robot de unos 44 mm de diámetro y 21 mm de alto y quiero revisar la fabricabilidad de una primera carcasa mecánica. Adjunto tres piezas separadas en STEP/STL y una probeta de ajustes. Antes de fabricar la carcasa completa, me gustaría validar la resina, las tolerancias y el mecanizado posterior de tres roscas M1.6.

¿Podéis revisar especialmente los alojamientos de guía con pared de 0,4 mm, los taladros de eje de 3,2 mm, las caras de apoyo y las holguras indicadas en este documento? No necesito una resina decorativa; busco un prototipo de ajuste con comportamiento mecánico documentado. Si alguna zona debe rediseñarse, prefiero saberlo antes de imprimir. Por favor, separad el presupuesto de la probeta y el de las tres piezas, e indicad el material, el poscurado, las tolerancias alcanzables y los acabados necesarios.

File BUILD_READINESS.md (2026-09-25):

# From packaging concept to working hardware

The selected Ø43 × 21 mm coplanar layout passes nominal CAD checks if the generated reports say so. It is not a tolerance-qualified assembly or a completed electronics design. There is no meaningful percentage-complete estimate: component selection and PCB placement can still change the shape.

## Body: a fit mock-up is nearer than an operational mover

The current model already separates a lower cup and lid, and has separate component supports and moving lift parts. But it lacks engineered joints and a demonstrated assembly path. Many supports are deliberately thin geometric allowances (including a 0.22 mm motor saddle), and cannot be treated as adequate printed load-bearing parts. Some clearances are around 0.1–0.3 mm before printer and purchased-part variation. Static noninterference is not proof of printability, strength or assembly access.

Proposed construction for the next mechanical revision:

1. Lower chassis holding motor saddles, independent axle supports, camera window and front charging cartridge.
2. Removable bridge/retainer clamping the motors and securing the servo cradle, with accessible screw paths.
3. Upper lid/PCB attachment; PCB should not be the sole structural load path for the servo or gears.
4. Separate magnet carriage and crank, with positive retention on pins and guides; removable battery restraint that does not squeeze the pouch.

This may be more than two printed parts even if the exterior looks like two pieces. Prefer screws/removable clamps for the first prototype. Reserve bosses and tool access before selecting screw sizes. Do not assume the existing envelope can absorb them. Wheels, axles and module-0.2 gears also require actual manufacture/part selection; tiny gears are not automatically suitable for the same printing process as the housing.

Before a functional print:

- Obtain exact purchasable N20 motor/gearbox/RPM variant, shaft drawing, X06N servo and spline/horn, lens/sensor/FPC, battery and termination drawings, wheels/tires/bearings, contact construction and magnet. Catalogue body dimensions alone omit tabs, plugs, lead exits and bend radii.
- Confirm the 17 × 14 × 7.2 mm candidate battery's high-current capability, maximum cycled envelope, protection arrangement and availability. Current CAD allowances are assumptions.
- Specify printer/process/material and print small fit coupons for shaft holes, motor pockets, joints and thin walls. Feed measured fit allowances back into the model; do not enlarge or shrink every part by an arbitrary universal tolerance.
- Check assembly sequence and service access: motors/axles/gears first, camera and leads, servo/lift and battery, PCB, then lid. Verify insertion sweeps, solder access, wire routing and fastener tool clearance. This order is a proposal, not a checked assembly procedure.
- Establish a stable floor support arrangement. Two wheels on one axle line alone do not establish a stable pitch support polygon; glides/casters or designed shell contacts need explicit clearances and loads.

Force cases for calculation and subsequent bench tests:

| Case | Needed evidence |
|---|---|
| Magnet separation | Magnetic force versus gap and lateral offset for actual steel/magnet/board; cam torque throughout stroke, guide friction, available servo torque at supply voltage |
| Lift structure | Crank pin shear/bending, tray and guides, servo cradle reaction; deflection compared with smallest running clearance |
| Driving / jam | Selected motor torque/current, wheel traction, axle bending, bearing retention, gear tooth/root loads and motor reaction paths |
| Docking / release | Spring curves and magnet pull curve through full retreat; traction margin, chassis pitch and contact compression stops |
| Handling / collision | Defined impact/load case, lid joints, screws and battery clearance; printed-material strength in intended orientation |

Use simple free-body/beam checks first, then FEA for the actual load-bearing geometry and print direction. Do not substitute isotropic bulk-plastic strength for tested printed parts. No structural FEA has been completed for this revision. A fit-only mock-up can precede those load checks, but a powered assembly should not be represented as qualified by it.

## PCB: still a functional block-space allocation

The CAD has a 41 mm board outline with large battery, servo and lift cutouts. Coloured IC/charger/boost boxes reserve volume; they are not placed real footprints, a netlist or routed circuitry. The full circular area is not usable PCB area, and narrow remaining bridges constrain routing and stiffness. We have not yet proved all required electronics fit.

Required decisions before a meaningful placement study:

- ESP32 variant, memory requirements, clock and reset/boot/programming circuitry, antenna location and keepouts. Metal motors, battery and magnets nearby make radio placement a genuine packaging constraint.
- Actual camera sensor and lens, interface, rails, clock, FPC/connector, required image rate and firmware resources. Optical working distance remains unproven.
- Two motor drivers sized from selected motor stall/start currents, chosen PWM/control scheme, optional encoder needs and connectors/solder points.
- Servo supply and transient load; determine whether the battery can supply it directly or needs conversion, and reserve inductor/capacitor height and copper area.
- Charger, battery protection, charge-current setting, power-path behaviour, low-battery measurement/fuel gauge, switches, test/programming pads and docking input protection.
- A complete power budget covering Wi-Fi/camera, motor startup, servo loading and any coils, including battery voltage sag and converter losses.
- Define what the four resonance coils actually do: inductance, frequency, Q, conductor geometry, capacitors, excitation/sensing circuits and copper/metal keepouts. Their visible rings are geometric placeholders, not an electrically designed subsystem. An initial board may explicitly reserve coils without populating their eventual circuits, but that would not confirm the final all-functions board fits.

Suggested sequence:

1. Freeze candidate component list and interface/power requirements; verify the electrical subassemblies with evaluation boards or bench wiring.
2. Create a complete schematic with real part numbers and footprints, including every passive and test point.
3. Import the current mechanical outline and height zones; perform a real placement and routing feasibility study (a 4-layer board is a candidate, not yet a requirement or proven solution).
4. Export the PCB assembly STEP back into this CAD; revise mounts, cutouts, camera flex routing, coil/antenna clearances and assembly access together.
5. Route, run electrical/design-rule checks, review return paths, thermal/current paths and manufacturability, then order a first assembled revision.
6. Bring up charging, power rails and MCU before motors/servo; measure startup brownouts, radio/camera performance and coil interaction. Revise board/body based on measured problems.

Recommendation: stop squeezing the envelope until the exact-part and real-PCB-placement steps are done. Keep Ø43 × 21 mm as a target, not a promise. Printing a larger accessible test chassis may accelerate validation while compact packaging develops. The PCB and enclosure must be iterated together; finalizing one before placing the other risks rework.

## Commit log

2026-09-24 Publish 40 mm chess mover interactive CAD viewer
2026-09-24 Add thin 45 mm mover with optional enclosure and camera opening
2026-09-24 Repack mover to 43 mm and document lift actuator sizing
2026-09-24 Fit KST X06 and reduce installed mover height to 20 mm
2026-09-24 Clarify historical actuator comparison after KST selection
2026-09-24 Add 100 mAh battery mover and charging dock viewer
    [dock.step, height_comparison.csv]
2026-09-25 Compare coplanar and bottom-battery mover CAD layouts
    [dock.step, layout_comparison.csv, mass_moment_sensitivity.csv]
2026-09-25 Add coplanar rail-charging concept and hardware readiness plan
    [components.csv, dock.step]
2026-09-25 Add detailed three-part mover body and print review package
    [components.csv, dock.step, fit_schedule.csv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]
